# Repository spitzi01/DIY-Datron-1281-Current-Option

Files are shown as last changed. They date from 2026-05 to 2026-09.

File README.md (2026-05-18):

# DIY-Datron-1281-Current-Option
Add current measurement capabilities to your Datron 1281

I bought a defective Datron 1281. Sadly there was no option installed. So replicated the current measurement board as closely as I could. Most of the parts are still avaiable. The CLA3106 ASIC can be replaced with my CPLD replacement. The only problems are the JFETs for switching the low current ranges and the shunt resistors. The original JFETs were replaced with similar off-the-shelf ones. The shunt resistors are the most expensive part of this project, but there is no real other choice than Vishay foil resistors. Some resistors are custom ordered from Texas Components. The PCB features full mechanical compatibility to the original board and all guard traces.

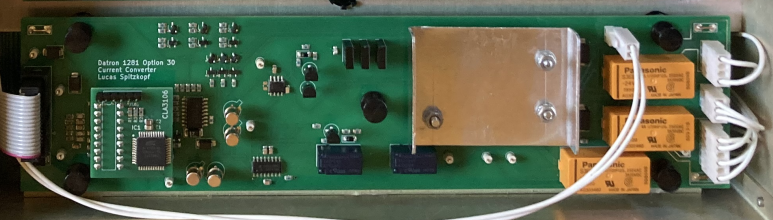
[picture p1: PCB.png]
DIY Current Option in Datron 1281


I did some noise and linearity measurements with a DIY multifunction calibrator which uses a AD5791B and a ADR1000. The visible INL is due to the DAC INL. The noise of the 100mA range for example is 0,5µA pk2pk and 0,12µA rms. It is very possible that these measurements describe the performance of the calibrator. To know for sure, I would need a known current source.

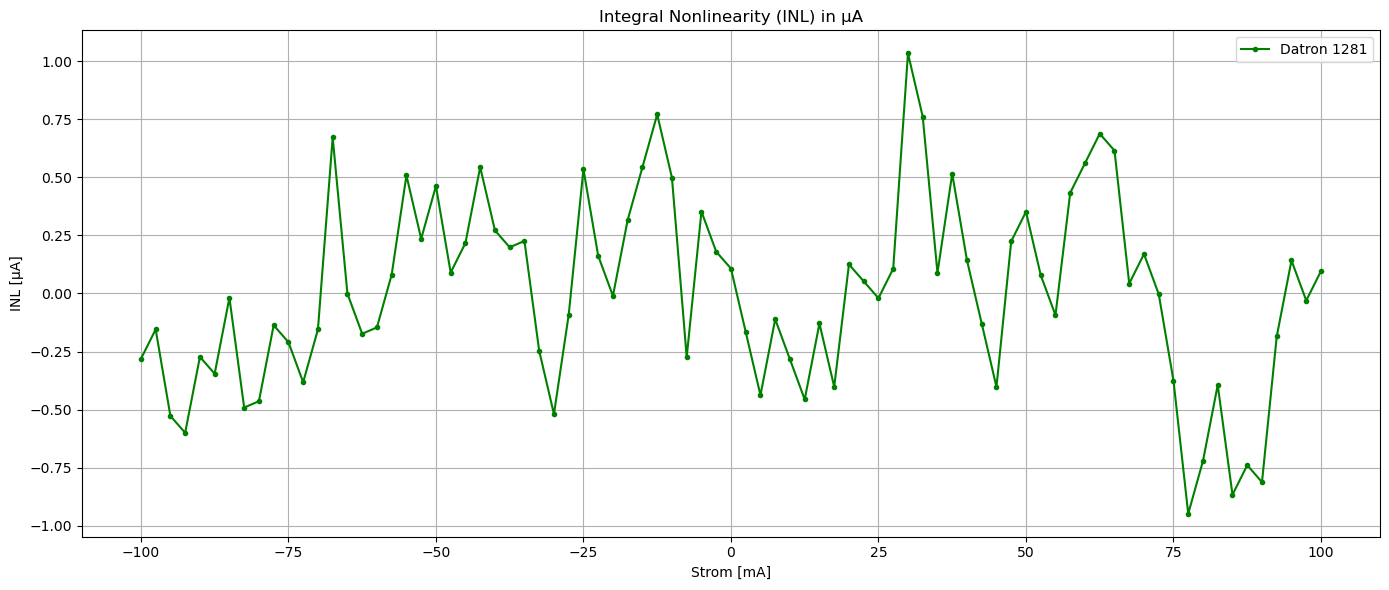
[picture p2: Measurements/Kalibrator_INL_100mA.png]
INL of the 100mA range


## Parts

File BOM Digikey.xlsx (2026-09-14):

Index | Menge | Teilenummer | Hersteller-Teilenummer | Beschreibung
1 | 4 | RS3G-FDICT-ND | RS3G-13-F | DIODE GEN PURP 400V 3A SMC
2 | 2 | SACB15CT-ND | SACB15 | TVS DIODE 15VWM 23.6VC SMB
3 | 1 | 4878-ZMY10CT-ND | ZMY10 | DIODE ZENER 10V 1.3W DO213AB
4 | 4 | 4004-PAD100TO-723L-ND | PAD100 TO-72 3L | DIODE STANDARD 45V 50MA TO723
5 | 1 | SACB5.0CT-ND | SACB5.0 | TVS DIODE 5VWM 10VC SMB
6 | 2 | FDLL3595CT-ND | FDLL3595 | DIODE STANDARD 125V 200MA SOD80
7 | 1 | DG211BDY-T1-E3CT-ND | DG211BDY-T1-E3 | IC SWITCH SPST-NCX4 85OHM 16SOIC
8 | 7 | 448-BSS84IXUSA1CT-ND | BSS84IXUSA1 | BSS84IXUSA1
9 | 3 | BC807-25LT3GOSCT-ND | BC807-25LT3G | TRANS PNP 45V 0.5A SOT23-3
10 | 3 | BC817-25LT3GOSCT-ND | BC817-25LT3G | TRANS NPN 45V 0.5A SOT23-3
11 | 1 | 296-ULN2004ANSRCT-ND | ULN2004ANSR | TRANS 7NPN DARL 50V 0.5A 16SO
12 | 2 | 255-1033-5-ND | TX2-24V | RELAY TELECOM DPDT 2A 24V
13 | 1 | MC33171DR2GOSCT-ND | MC33171DR2G | IC OPAMP GP 1 CIRCUIT 8SOIC
14 | 1 | WM2748-ND | 0022292061 | CONN HEADER VERT 6POS 2.54MM
15 | 1 | WM2745-ND | 0022292031 | CONN HEADER VERT 3POS 2.54MM
16 | 1 | WM2746-ND | 0022292041 | CONN HEADER VERT 4POS 2.54MM
17 | 1 | WM2744-ND | 0022292021 | CONN HEADER VERT 2POS 2.54MM
18 | 1 | 1655-S1ACT-ND | S1A | DIODE GEN PURP 50V 1A SMA
19 | 1 | 732-2095-ND | 61201621621 | CONN HEADER VERT 16POS 2.54MM
20 | 2 | 13-CC0805JPNPO0BN330CT-ND | CC0805JPNPO0BN330 | CAP CER 33PF 100V C0G/NPO 0805
21 | 6 | 1276-6840-1-ND | CL21B104KCFNNNE | CAP CER 0.1UF 100V X7R 0805
22 | 2 | 1276-1169-1-ND | CL21B102KCANNNC | CAP CER 1000PF 100V X7R 0805
23 | 1 | 4713-GMC21CG150J100NTCT-ND | GMC21CG150J100NT | CAP0805 COG 15PF 5% 100V
24 | 1 | 399-C0805C471J1HACTUCT-ND | C0805C471J1HACTU | CAP CER 470PF 100V X8R 0805
25 | 7 | 2019-RK73H2ATTD1000FCT-ND | RK73H2ATTD1000F | RES 100 OHM 1% 1/4W 0805
26 | 10 | 2019-RK73H2ATTD1001FCT-ND | RK73H2ATTD1001F | RES 1K OHM 1% 1/4W 0805
27 | 27 | 2019-RK73H2ATTE1003FCT-ND | RK73H2ATTE1003F | RES 100K OHM 1% 1/4W 0805
28 | 1 | 2019-RK73H2ATTD5623FCT-ND | RK73H2ATTD5623F | RES 562K OHM 1% 1/4W 0805
29 | 1 | 2019-RK73H2ATTD6813FCT-ND | RK73H2ATTD6813F | RES 681K OHM 1% 1/4W 0805
30 | 3 | 2019-RK73H2ATTD1002FCT-ND | RK73H2ATTD1002F | RES 10K OHM 1% 1/4W 0805
31 | 3 | 2019-RK73H2ATTD2742FCT-ND | RK73H2ATTD2742F | RES 27.4K OHM 1% 1/4W 0805
32 | 3 | 2019-RK73H2ATTD1004FCT-ND | RK73H2ATTD1004F | RES 1M OHM 1% 1/4W 0805
33 | 1 | 2019-RK73H2ATTD2201FCT-ND | RK73H2ATTD2201F | RES 2.2K OHM 1% 1/4W 0805
34 | 1 | 708-2497-ND | FX0454 | FUSE HLDR CART 250V 10A PNL MNT
35 | 2 | 732-2103-ND | 61201623021 | CONN RCPT 16POS IDC 28AWG GOLD
36 | 2 | WM2004-ND | 0022013067 | CONN RCPT HSG 6POS 2.54MM
37 | 2 | 900-0022013037-ND | 0022013037 | CONN RCPT HSG 3POS 2.54MM
38 | 2 | WM2002-ND | 0022013047 | CONN RCPT HSG 4POS 2.54MM
39 | 20 | WM2625CT-ND | 0008500031 | CONN 22-30AWG CRIMP TIN
40 | 1 | 900-0022013027-ND | 0022013027 | CONN RCPT HSG 2POS 2.54MM
41 | 11 | 36-5002-ND | 5002 | PC TEST POINT MINIATURE WHITE
42 | 5 | RPC1394-ND | SLG-2M-B | GROMMET SNAP LATCH BLACK
43 | 5 | RPC1398-ND | SLPB-2M-B | SNAP LATCH BLACK 0.142" - 0.228"
44 | 1 | 17-2485264-5-ND | 2485264-5 | DIP IC SOCKET 18P,SN
45 | 2 | 255-1888-ND | S3EB-24V | RELAY GEN PURPOSE 4PST 4A 24V
46 | 1 | 255-1740-ND | S2EB-24V | RELAY GEN PURPOSE 4PST 4A 24V
47 | 3 | J111FS-ND | J111 | JFET N-CH 35V TO92-3
48 | 1 | F1726-ND | 021701.6MXP | FUSE GLASS 1.6A 250VAC 5X20MM
49 | 3 | BSS138NH6327XTSA2CT-ND | BSS138NH6327XTSA2 | MOSFET N-CH 60V 230MA SOT23-3

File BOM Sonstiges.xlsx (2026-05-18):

Cable
5m | PTFE Cable 1x AWG20
10cm | Flat IDC Cable 16 Poles
Precision Resistors
1x | Y09430R10000F0L | 0,1 Ohm | 1% | 3 ppm/°C
1x | VPR221ZT | 1 Ohm | 0.02% | 0,2 ppm/°C
1x | Z201 | 9 Ohm | 0.05% | 0,2 ppm/°C
1x | Z201 | 90 Ohm | 0.05% | 0,2 ppm/°C
1x | Z201 | 900 Ohm | 0.05% | 0,2 ppm/°C

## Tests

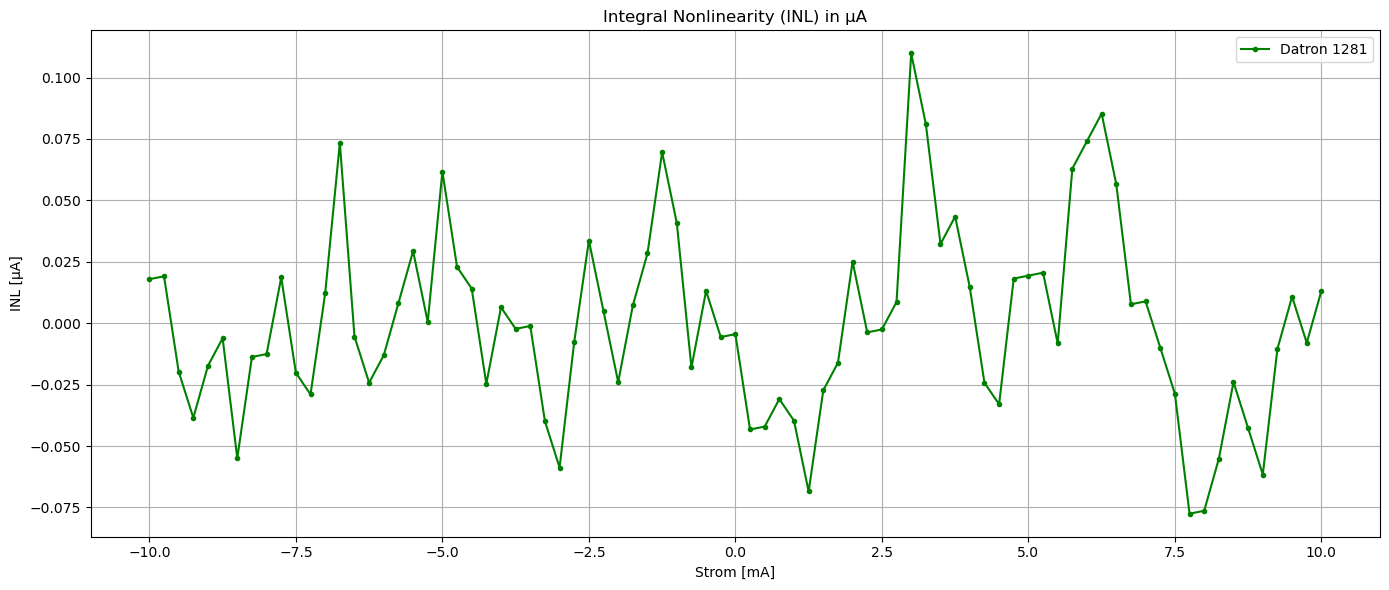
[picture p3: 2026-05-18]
Measurements/Kalibrator_INL_10mA.png

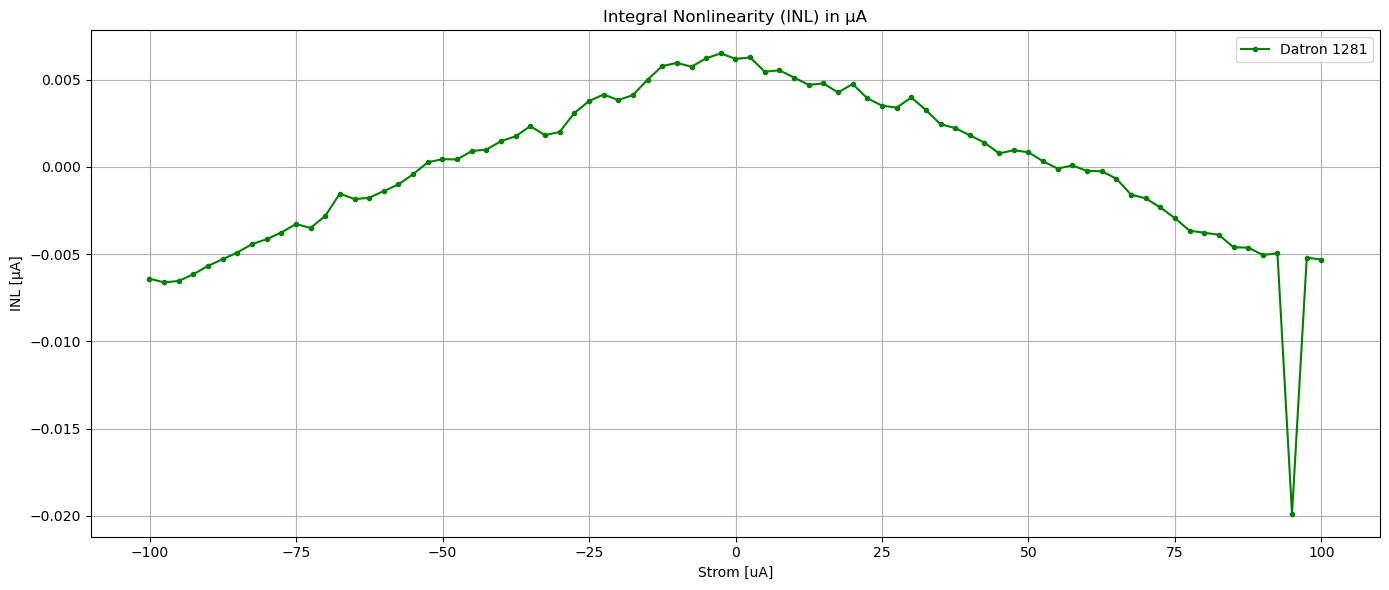
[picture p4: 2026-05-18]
Measurements/Kalibrator_INL_100uA.png

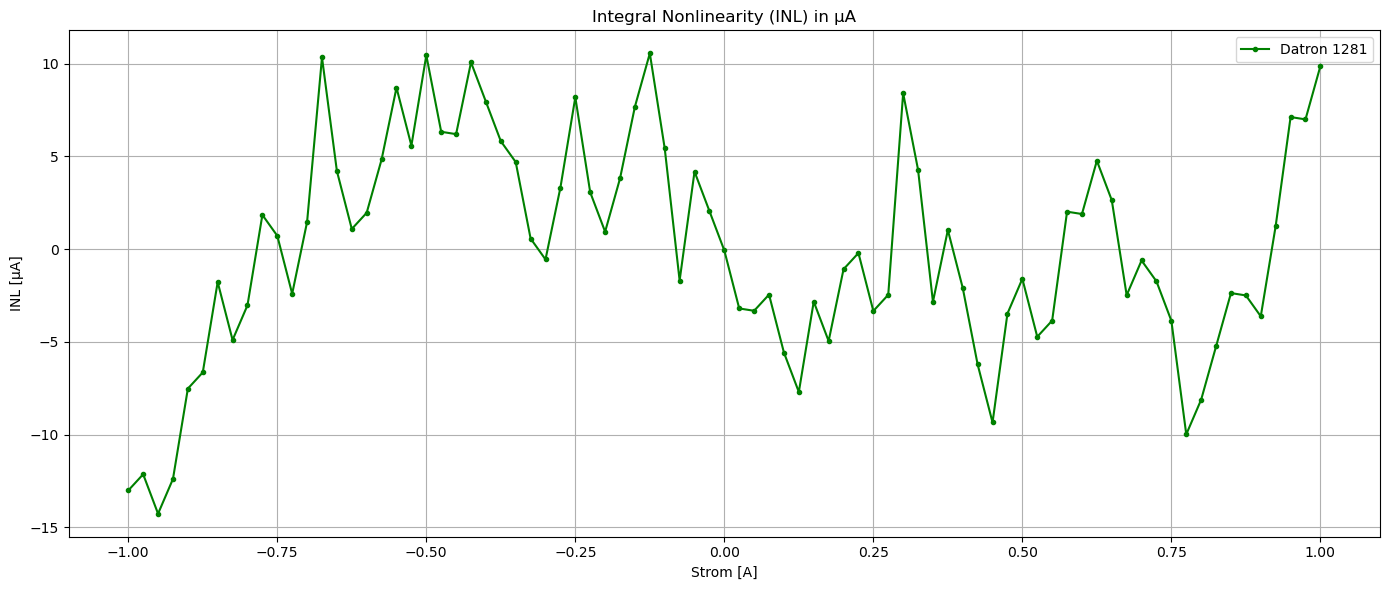
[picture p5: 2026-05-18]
Measurements/Kalibrator_INL_1A.png

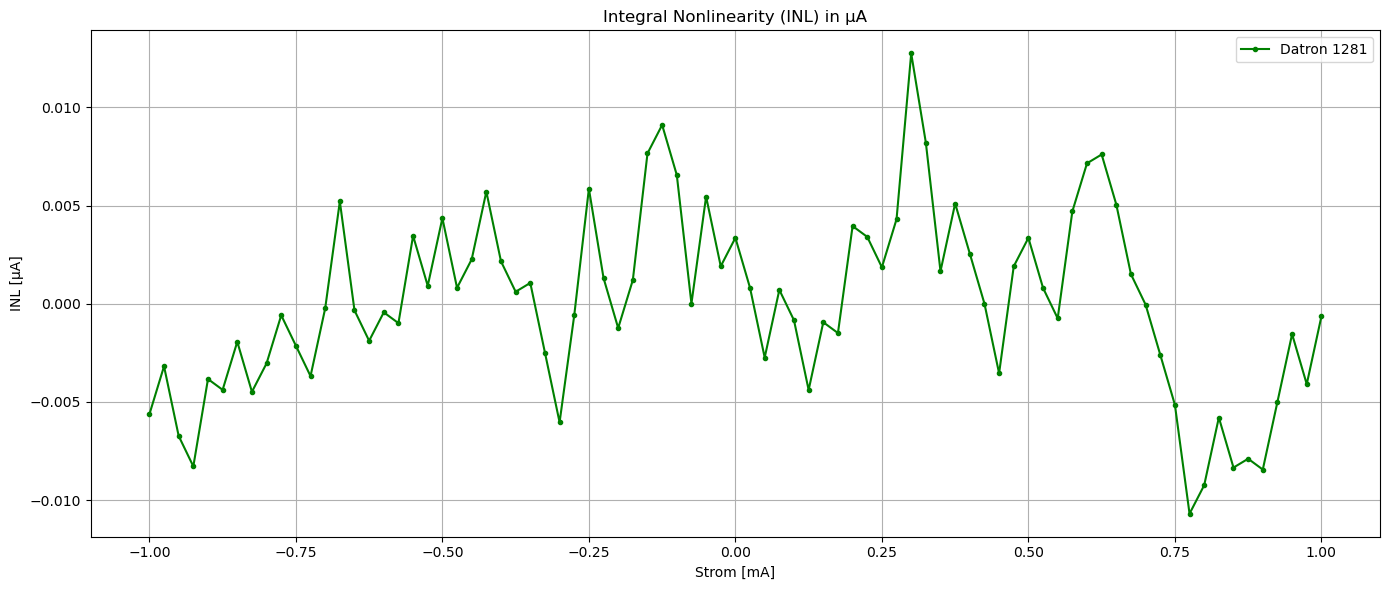
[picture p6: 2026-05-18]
Measurements/Kalibrator_INL_1mA.png

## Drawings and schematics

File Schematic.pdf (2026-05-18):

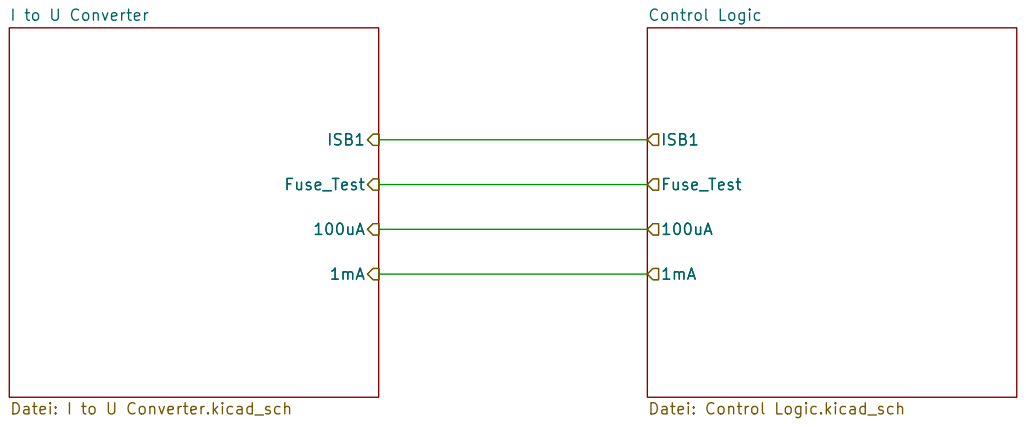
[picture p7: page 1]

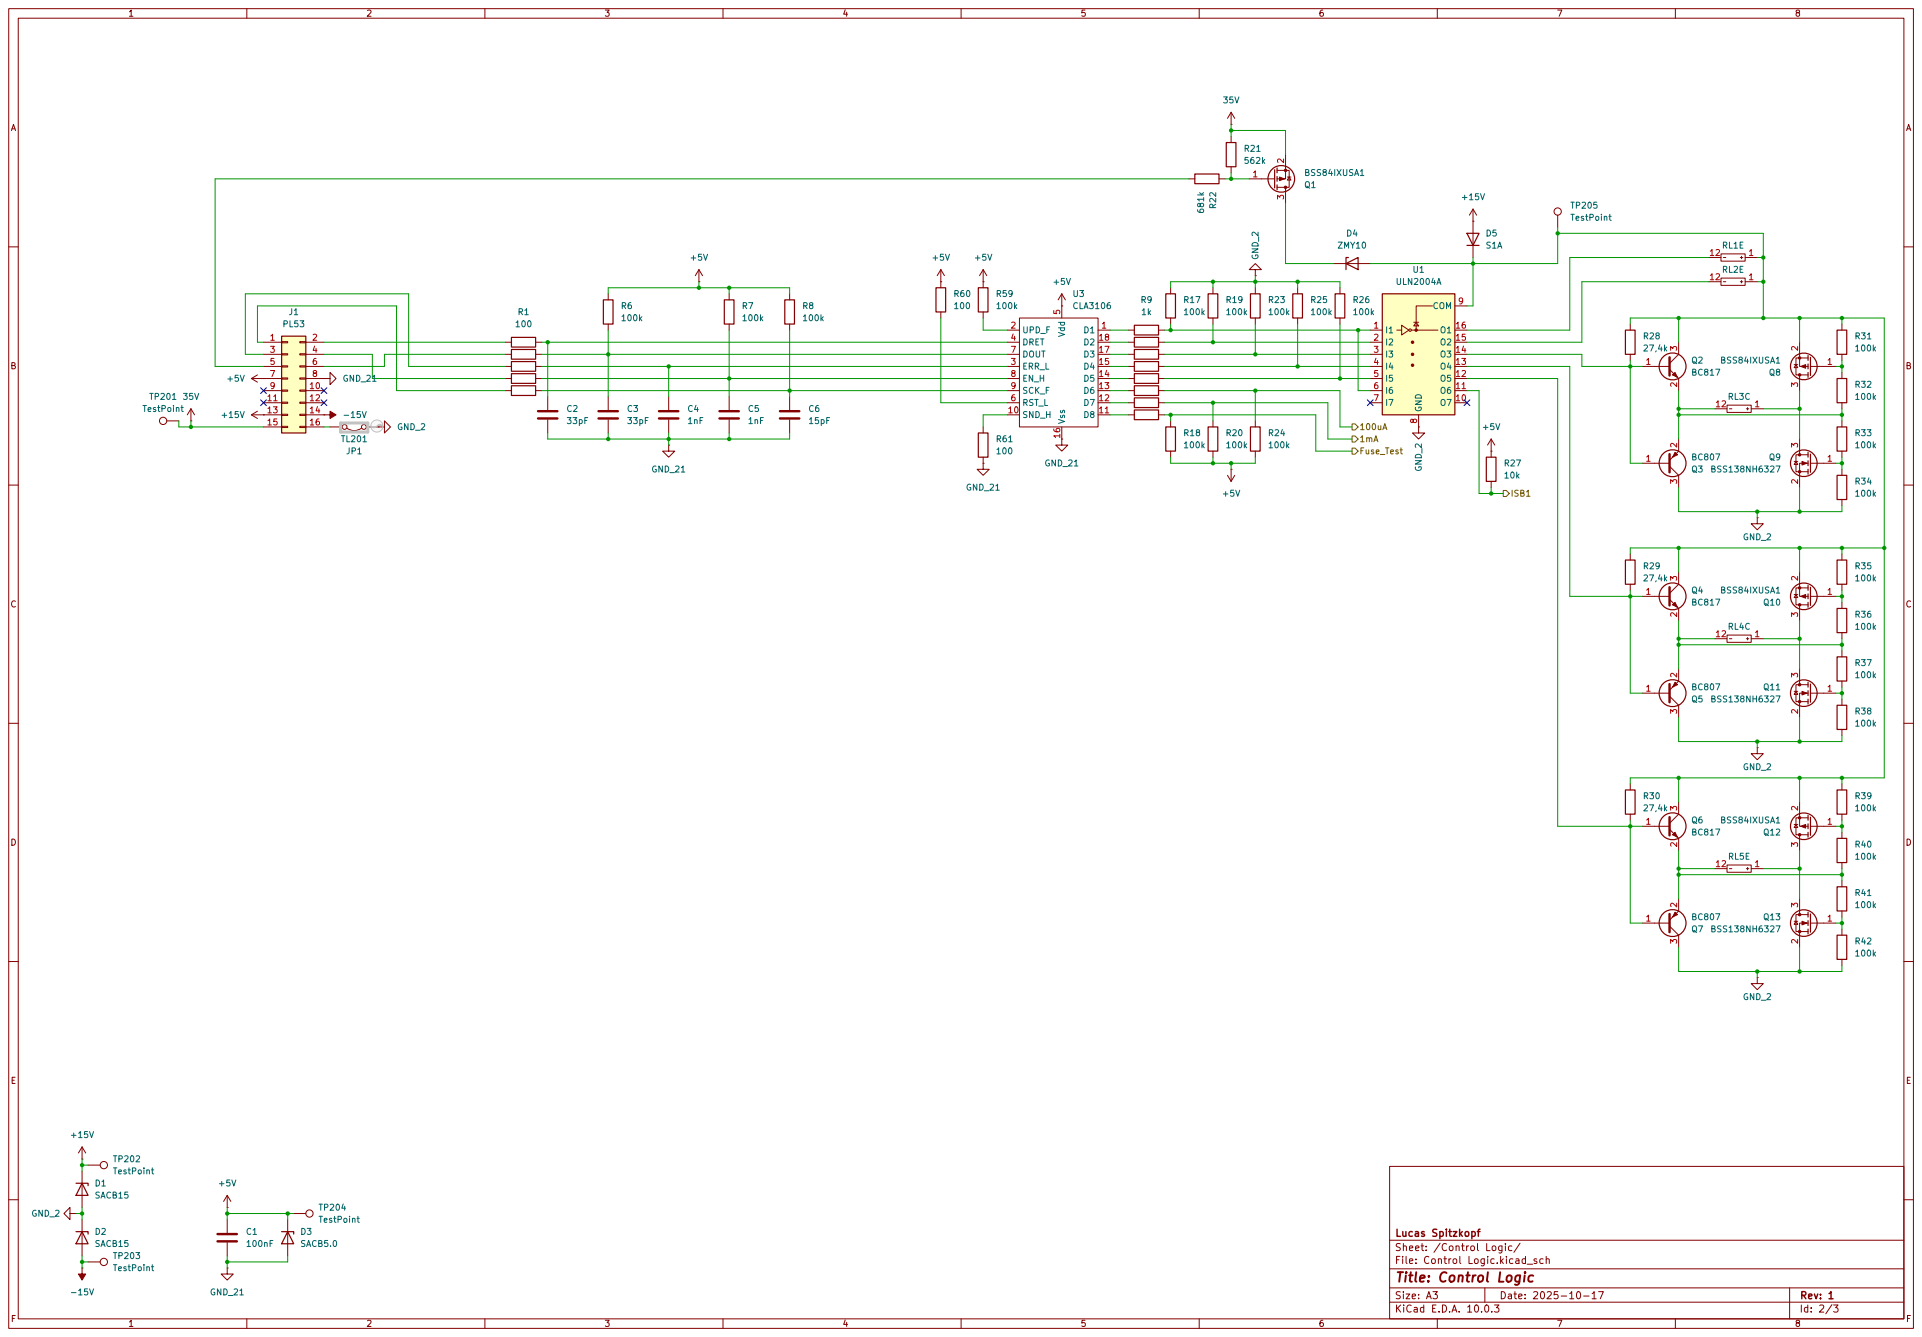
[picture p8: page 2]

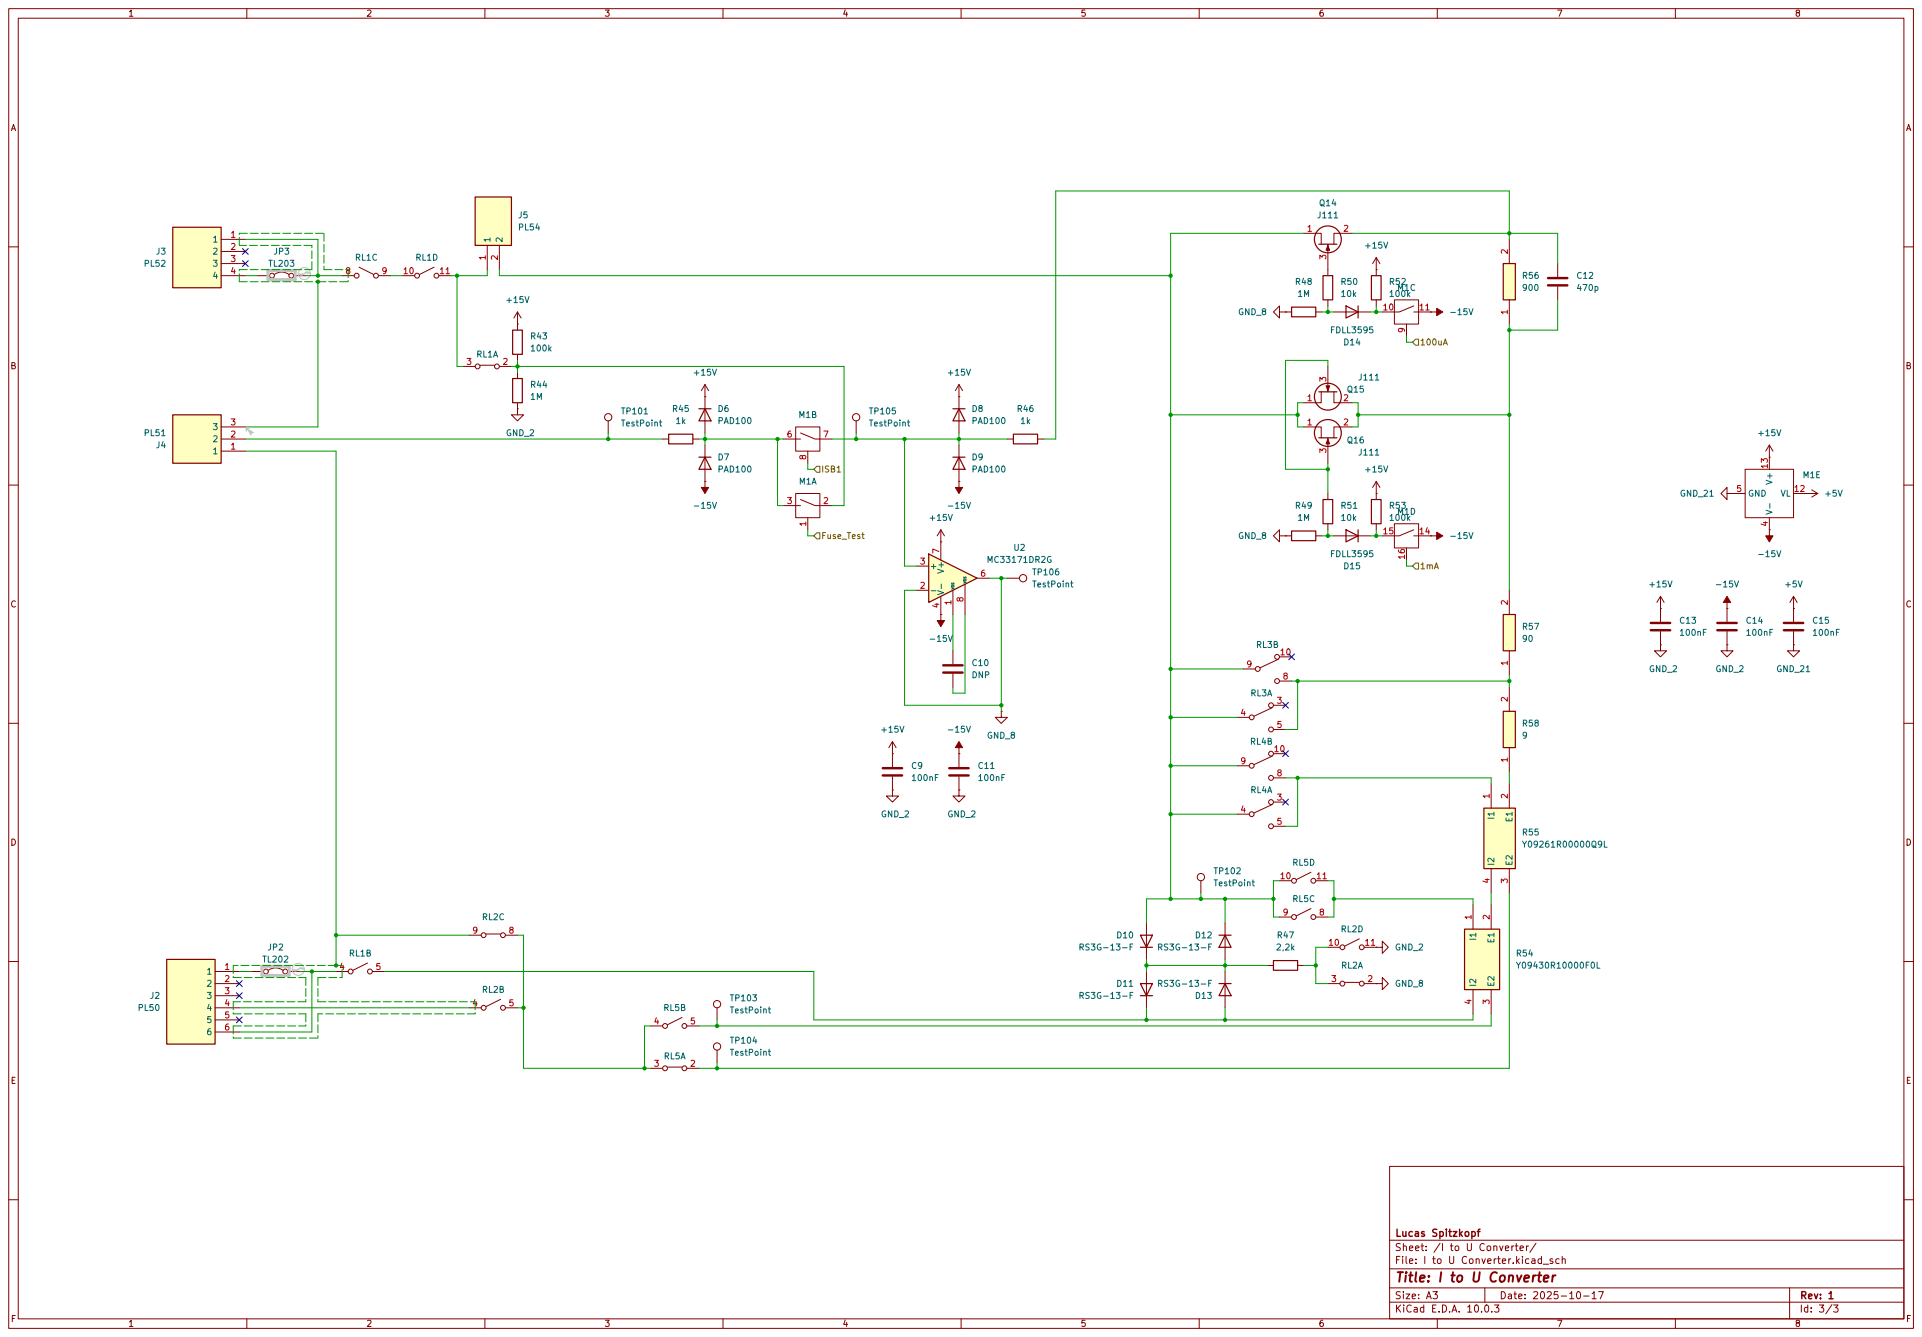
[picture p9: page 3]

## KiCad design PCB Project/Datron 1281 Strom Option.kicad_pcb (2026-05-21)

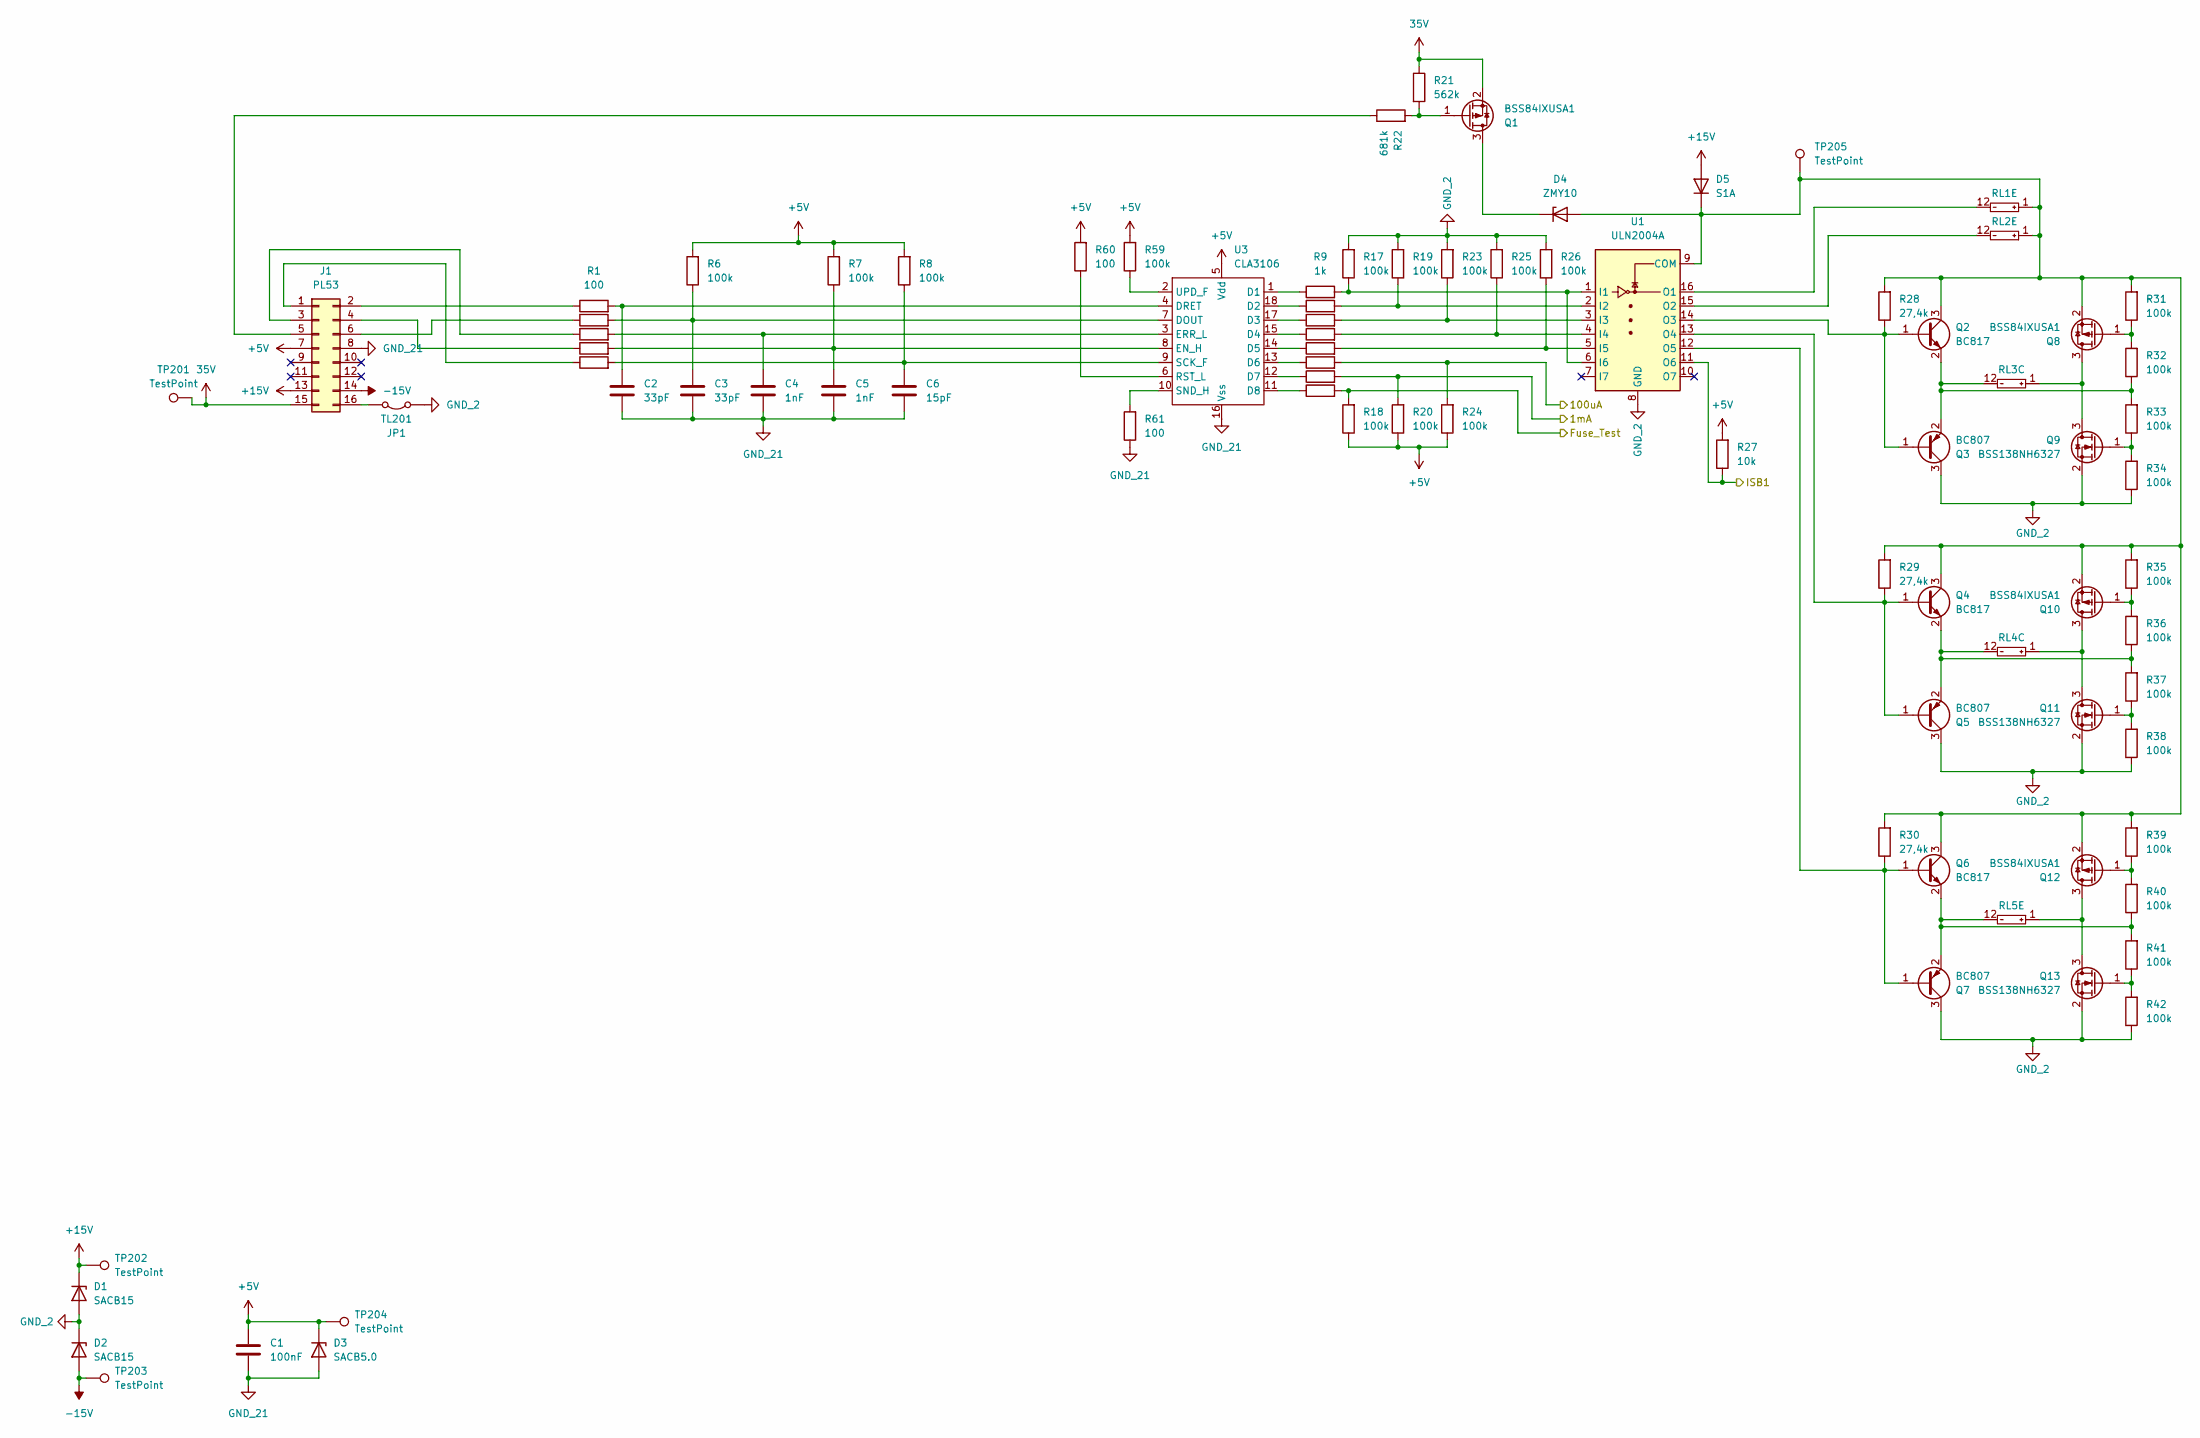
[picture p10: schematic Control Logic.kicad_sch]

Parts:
C1: 100nF; C_0805_2012Metric
C2, C3: 33pF; C_0805_2012Metric
C4, C5: 1nF; C_0805_2012Metric
C6: 15pF; C_0805_2012Metric
D1, D2: SACB15; D_SMB
D3: SACB5.0; D_SMB
D4: ZMY10; D_MELF
D5: S1A; D_SMA
J1: PL53; IDC-Header_2x08_P2.54mm_Vertical
JP1: TL201; TestPoint_2Pads_Pitch5.08mm_Drill1.3mm
Q1, Q8, Q10, Q12: BSS84IXUSA1; SOT-23-3
Q2, Q4, Q6: BC817; SOT-23
Q3, Q5, Q7: BC807; SOT-23
Q9, Q11, Q13: BSS138NH6327; SOT-23-3
R1, R2, R3, R4, R5, R60, R61: 100; R_0805_2012Metric
R6, R7, R8, R17, R18, R19, R20, R23, R24, R25, R26, R31, R32, R33, R34, R35, R36, R37, R38, R39, R40, R41, R42, R59: 100k; R_0805_2012Metric
R9, R10, R11, R12, R13, R14, R15, R16: 1k; R_0805_2012Metric
R21: 562k; R_0805_2012Metric
R22: 681k; R_0805_2012Metric
R27: 10k; R_0805_2012Metric
R28, R29, R30: 27,4k; R_0805_2012Metric
RL1, RL5: S3-DC24V; S3DC24V; Manufacturer_Part_Number S3-DC24V
RL2: S2-DC24V; S3DC24V; Manufacturer_Part_Number S2-DC24V
RL3, RL4: TX2-24V; Mouser Part Number 769-TX2-24V
TP201, TP202, TP203, TP204, TP205: TestPoint; TestPoint_Loop_D2.50mm_Drill1.0mm
U1: ULN2004A; SOIC-16W_5.3x10.2mm_P1.27mm
U3: CLA3106; DIP-18_W7.62mm_LongPads

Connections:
35V: J1.15, Q1.2 (S), R21.1, TP201.1
+5V: C1.1, D3.1 (K), J1.7, R6.2, R7.2, R8.2, R18.1, R20.1, R24.1, R27.2, R59.2, R60.2, TP204.1, U3.5 (Vdd); also elsewhere on the board
+15V: D1.1 (K), D5.2 (A), J1.13, TP202.1; also elsewhere on the board
-15V: D2.2 (A), J1.14, TP203.1; also elsewhere on the board
/Control Logic/1mA: R15.2, R20.2; also elsewhere on the board
/Control Logic/100uA: R14.2, R24.2; also elsewhere on the board
/Control Logic/Fuse_Test: R16.2, R18.2; also elsewhere on the board
/Control Logic/ISB1: R27.1, U1.11 (O6); also elsewhere on the board
GND_2: D1.2 (A), D2.1 (K), JP1.1 (A), Q3.3 (C), Q5.3 (C), Q7.3 (C), Q9.2 (S), Q11.2 (S), Q13.2 (S), R17.2, R19.2, R23.2, R25.2, R26.2, R34.1, R38.1, R42.1, U1.8 (GND); also elsewhere on the board
GND_21: C1.2, C2.2, C3.2, C4.2, C5.2, C6.2, D3.2 (A), J1.8, R61.1, U3.16 (Vss); also elsewhere on the board
unnamed: D4.2 (A), D5.1 (K), Q2.3 (C), Q4.3 (C), Q6.3 (C), Q8.2 (S), Q10.2 (S), Q12.2 (S), R28.2, R29.2, R30.2, R31.2, R35.2, R39.2, RL1.1, RL2.1, TP205.1, U1.9 (COM)
unnamed: D4.1 (K), Q1.3 (D)
unnamed: J1.1, R5.1
unnamed: J1.2, R1.1
unnamed: J1.3, R3.1
unnamed: J1.4, R4.1
unnamed: J1.5, R22.1
unnamed: J1.6, R2.1
unnamed: J1.16, JP1.2 (B)
unnamed: Q1.1 (G), R21.2, R22.2
unnamed: Q2.1 (B), Q3.1 (B), R28.1, U1.14 (O3)
unnamed: Q2.2 (E), Q3.2 (E), R32.1, R33.2, RL3.12
unnamed: Q4.1 (B), Q5.1 (B), R29.1, U1.13 (O4)
unnamed: Q4.2 (E), Q5.2 (E), R36.1, R37.2, RL4.12
unnamed: Q6.1 (B), Q7.1 (B), R30.1, U1.12 (O5)
unnamed: Q6.2 (E), Q7.2 (E), R40.1, R41.2, RL5.12
unnamed: Q8.3 (D), Q9.3 (D), RL3.1
unnamed: Q8.1 (G), R31.1, R32.2
unnamed: Q9.1 (G), R33.1, R34.2
unnamed: Q10.3 (D), Q11.3 (D), RL4.1
unnamed: Q10.1 (G), R35.1, R36.2
unnamed: Q11.1 (G), R37.1, R38.2
unnamed: Q12.3 (D), Q13.3 (D), RL5.1
unnamed: Q12.1 (G), R39.1, R40.2
unnamed: Q13.1 (G), R41.1, R42.2
unnamed: R9.2, R17.1, U1.1 (I1), U1.6 (I6)
unnamed: R10.2, R19.1, U1.2 (I2)
unnamed: R11.2, R23.1, U1.3 (I3)
unnamed: R12.2, R25.1, U1.4 (I4)
unnamed: R13.2, R26.1, U1.5 (I5)
unnamed: RL1.12, U1.16 (O1)
unnamed: RL2.12, U1.15 (O2)
unnamed: R9.1, U3.1 (D1)
unnamed: R10.1, U3.18 (D2)
unnamed: R11.1, U3.17 (D3)
unnamed: R12.1, U3.15 (D4)
unnamed: R13.1, U3.14 (D5)
unnamed: R14.1, U3.13 (D6)
unnamed: R15.1, U3.12 (D7)
unnamed: R16.1, U3.11 (D8)
unnamed: C3.1, R2.2, R6.1, U3.7 (DOUT)
unnamed: C2.1, R1.2, U3.4 (DRET)
unnamed: C5.1, R4.2, R7.1, U3.8 (EN_H)
unnamed: C4.1, R3.2, U3.3 (ERR_L)
unnamed: R60.1, U3.6 (RST_L)
unnamed: C6.1, R5.2, R8.1, U3.9 (SCK_F)
unnamed: R61.2, U3.10 (SND_H)
unnamed: R59.1, U3.2 (UPD_F)

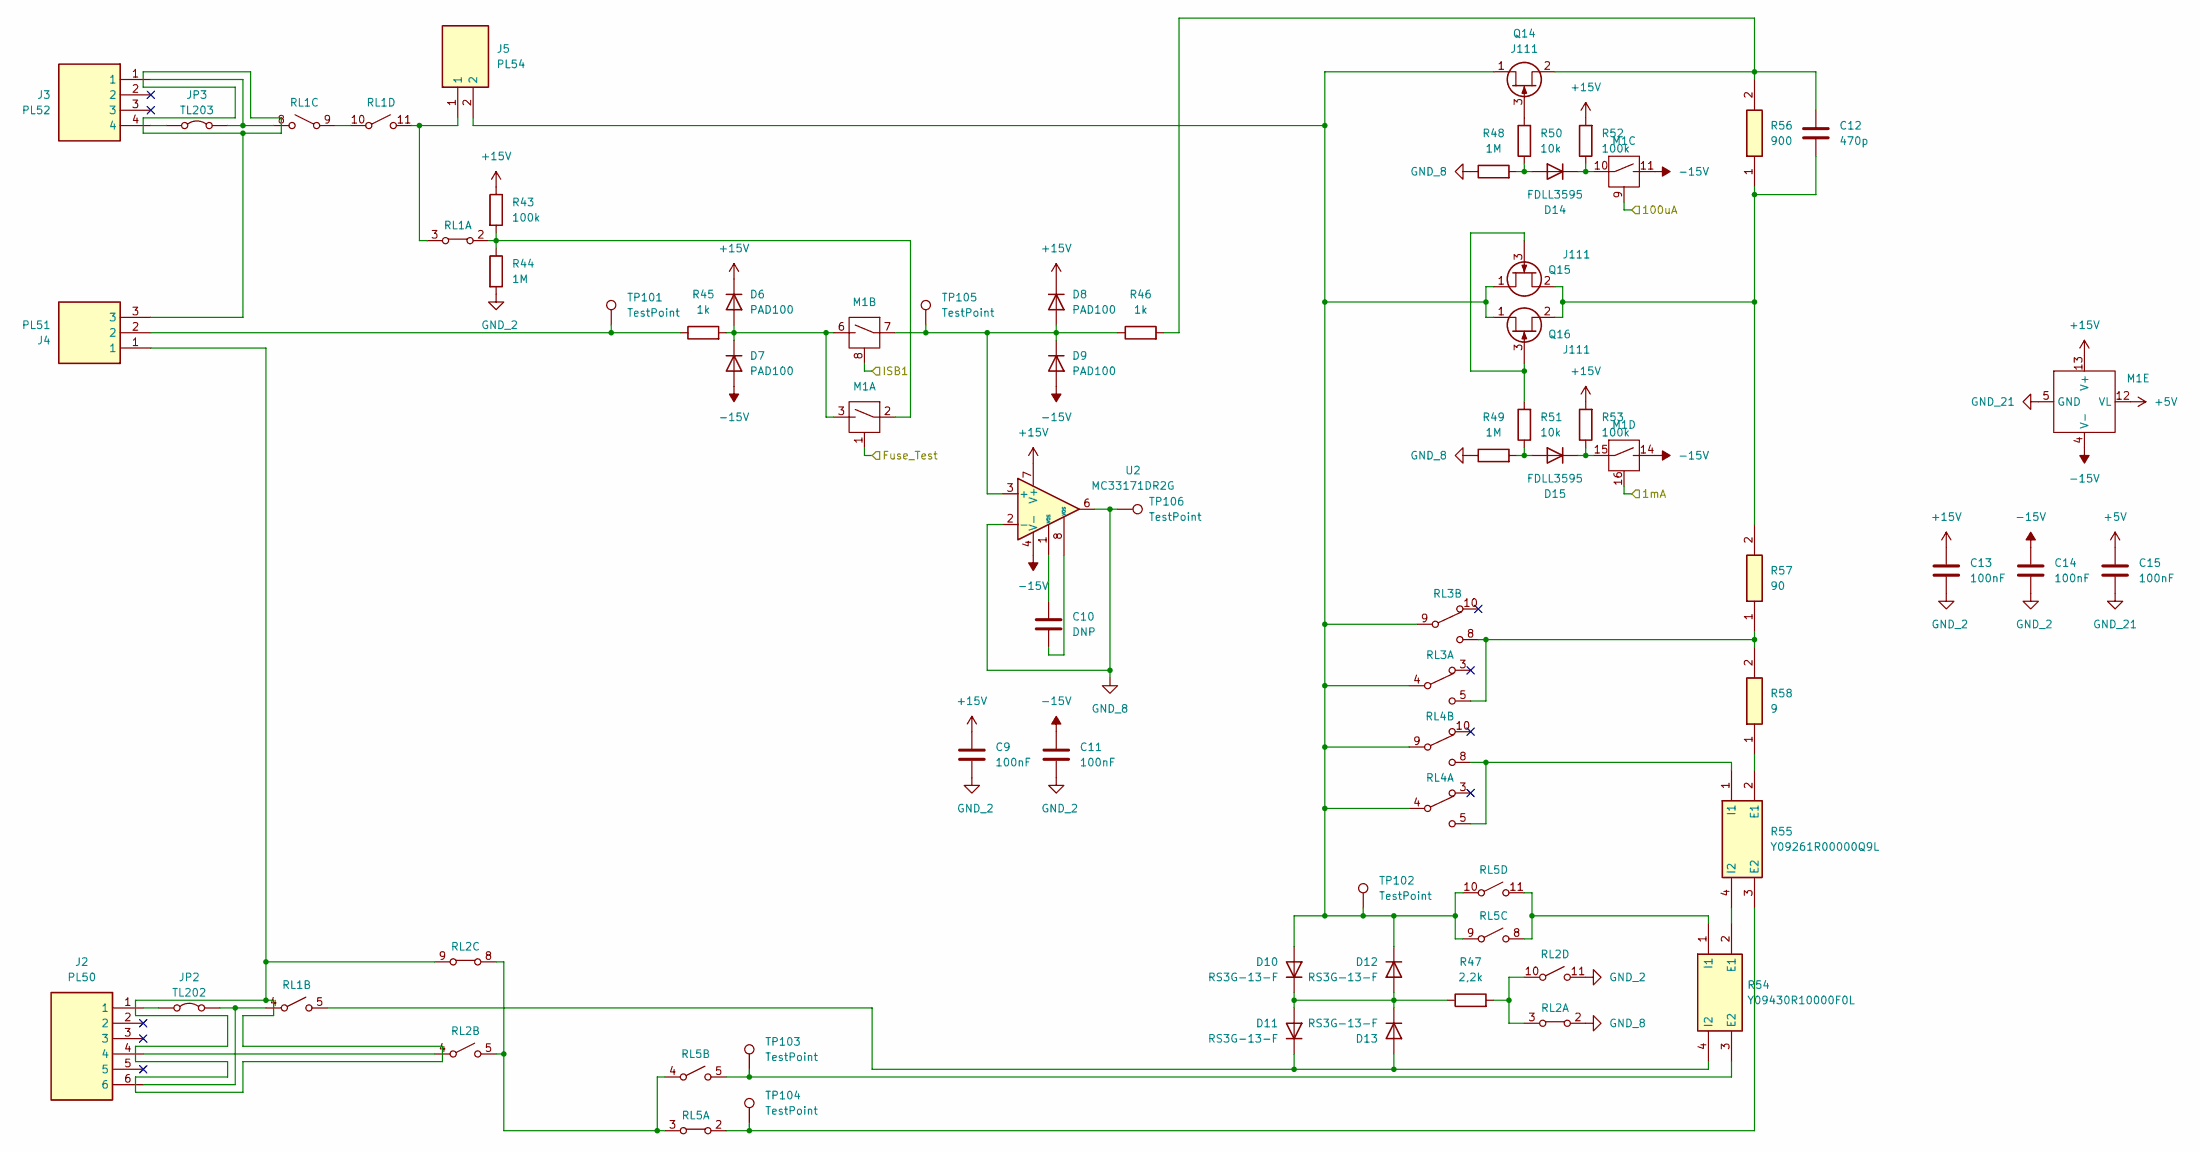
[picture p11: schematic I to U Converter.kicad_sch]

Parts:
C9, C11, C13, C14, C15: 100nF; C_0805_2012Metric
C10: DNP; C_0805_2012Metric
C12: 470p; C_0805_2012Metric
D6, D7, D8, D9: PAD100; TO-72-3
D10, D11, D12, D13: RS3G-13-F; D_SMC
D14, D15: FDLL3595; D_MiniMELF
J2: PL50; HDRV6W64P0X254_1X6_1524X580X1205P; Mouser Part Number 538-22-29-2061
J3: PL52; SHDR4W64P0X254_1X4_1016X580X1170P; Mouser Part Number 538-22-29-2041
J4: PL51; SHDR3W64P0X254_1X3_762X580X1170P; Mouser Part Number 538-22-29-2031
J5: PL54; SHDR2W64P0X254_1X2_508X580X1170P; Mouser Part Number 538-22-29-2021
JP2: TL202; TestPoint_2Pads_Pitch5.08mm_Drill1.3mm
JP3: TL203; TestPoint_2Pads_Pitch5.08mm_Drill1.3mm
M1: DG211BDY; SOIC127P600X175-16N; Mouser Part Number 781-DG211BDY-E3
Q14, Q15, Q16: J111; TO-92
R43, R52, R53: 100k; R_0805_2012Metric
R44, R48, R49: 1M; R_0805_2012Metric
R45, R46: 1k; R_0805_2012Metric
R47: 2,2k; R_0805_2012Metric
R50, R51: 10k; R_0805_2012Metric
R54: Y09430R10000F0L; Mouser Part Number 71-Y09430R10000F0L
R55: Y09261R00000Q9L; TO254P401X1016X2196-4P; Mouser Part Number N/A
R56: 900; Y145310K0000V9L; Manufacturer_Part_Number Y145310K0000V9L; Mouser Part Number N/A
R57: 90; Y145310K0000V9L; Manufacturer_Part_Number Y145310K0000V9L; Mouser Part Number N/A
R58: 9; Y145310K0000V9L; Manufacturer_Part_Number Y145310K0000V9L; Mouser Part Number N/A
RL1, RL5: S3-DC24V; S3DC24V; Manufacturer_Part_Number S3-DC24V
RL2: S2-DC24V; S3DC24V; Manufacturer_Part_Number S2-DC24V
RL3, RL4: TX2-24V; Mouser Part Number 769-TX2-24V
TP101, TP102, TP103, TP104, TP105, TP106: TestPoint; TestPoint_Loop_D2.50mm_Drill1.0mm
U2: MC33171DR2G; SOIC-8_3.9x4.9mm_P1.27mm

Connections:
+5V: C15.1, M1.12 (VL); also elsewhere on the board
+15V: C9.1, C13.1, D6.1 (K), D8.1 (K), M1.13 (V+), R43.1, R52.2, R53.2, U2.7 (V+); also elsewhere on the board
-15V: C11.1, C14.1, D7.2 (A), D9.2 (A), M1.4 (V-), M1.11, M1.14, U2.4 (V-); also elsewhere on the board
/Control Logic/1mA: M1.16; also elsewhere on the board
/Control Logic/100uA: M1.9; also elsewhere on the board
/Control Logic/Fuse_Test: M1.1; also elsewhere on the board
/Control Logic/ISB1: M1.8; also elsewhere on the board
GND_2: C9.2, C11.2, C13.2, C14.2, R44.2, RL2.11; also elsewhere on the board
GND_8: R48.1, R49.1, RL2.2, TP106.1, U2.2 (-), U2.6
GND_21: C15.2, M1.5 (GND); also elsewhere on the board
unnamed: C10.1, U2.1 (VOS)
unnamed: C10.2, U2.8 (VOS)
unnamed: D6.2 (A), D7.1 (K), M1.3, M1.6, R45.2
unnamed: D8.2 (A), D9.1 (K), M1.7, R46.1, TP105.1, U2.3 (+)
unnamed: D10.2 (A), D12.1 (K), J5.2, Q14.1 (D), Q15.1 (D), Q16.1 (D), RL3.4, RL3.9, RL4.4, RL4.9, RL5.9, RL5.10, TP102.1
unnamed: D10.1 (K), D11.2 (A), D12.2 (A), D13.1 (K), R47.1
unnamed: D11.1 (K), D13.2 (A), R54.4 (I2), RL1.5
unnamed: D14.2 (A), R48.2, R50.1
unnamed: D14.1 (K), M1.10, R52.1
unnamed: D15.2 (A), R49.2, R51.1
unnamed: D15.1 (K), M1.15, R53.1
unnamed: J2.4, RL2.4
unnamed: J4.1, RL2.9
unnamed: J4.2, R45.1, TP101.1
unnamed: J5.1, RL1.3, RL1.11
unnamed: J2.6, JP2.1 (A), RL1.4
unnamed: J2.1, JP2.2 (B)
unnamed: J3.1, JP3.1 (A), RL1.8
unnamed: J3.4, JP3.2 (B)
unnamed: M1.2, R43.2, R44.1, RL1.2
unnamed: Q14.3 (G), R50.2
unnamed: C12.1, Q14.2 (S), R46.2, R56.2
unnamed: Q15.3 (G), Q16.3 (G), R51.2
unnamed: C12.2, Q15.2 (S), Q16.2 (S), R56.1, R57.2
unnamed: R47.2, RL2.3, RL2.10
unnamed: R54.2 (E1), R55.4 (I2)
unnamed: R54.3 (E2), RL5.5, TP103.1
unnamed: R54.1 (I1), RL5.8, RL5.11
unnamed: R55.2 (E1), R58.1
unnamed: R55.3 (E2), RL5.2, TP104.1
unnamed: R55.1 (I1), RL4.5, RL4.8
unnamed: R57.1, R58.2, RL3.5, RL3.8
unnamed: RL1.9, RL1.10
unnamed: RL2.5, RL2.8, RL5.3, RL5.4

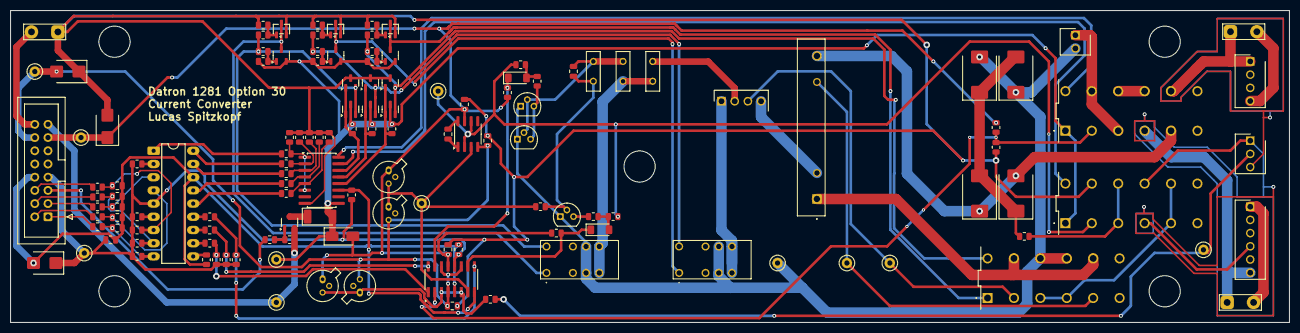
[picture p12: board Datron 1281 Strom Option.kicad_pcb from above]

Board: 2 copper layers, 246.0 x 60.0 mm, 133 parts (0 on the bottom side), 93 nets.
